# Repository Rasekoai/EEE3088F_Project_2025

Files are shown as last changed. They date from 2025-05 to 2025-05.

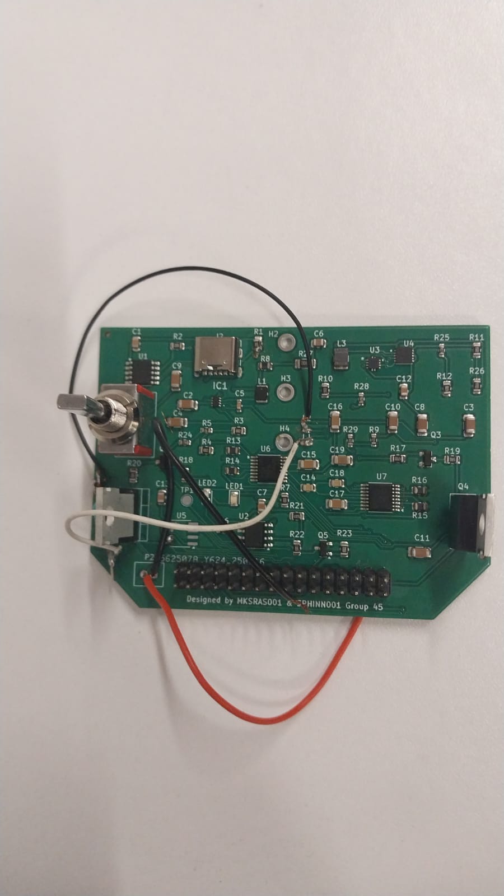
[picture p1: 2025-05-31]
Project files/PCB.jpg

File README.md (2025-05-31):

## EEE3088F 2025 Micromouse Power Module Project

## Overview
This repository contains the design and implementation of the power subsystem for the Micro-mouse robot. The power subsystem is designed to efficiently manage power distribution to motors and provide USB connectivity for control interfaces.

## System Requirements

### Motor Control
- **Bidirectional operation** of up to 4 motors 
- **Motor specifications**:
  - 2x main brushed DC motors - 200mA max current draw at 15V battery
  - 2x auxiliary motors - 50mA each

### Battery Management
- **Battery**: 4.2V Lithium ion battery 
- **INA219** implementation for monitoring the battery on the I2C Bus
- **Charging**: Support for battery charging from the 5V input 
- **Dual charging modes**:
  - Higher charging current for battery (600mA)
  - Lower charging current for battery (100mA)

### USB Interface
- **Integrated USB-C port** for 5V output from the USB Host

### Power Control
- **ON/OFF switch**:
  - OFF state: Battery draw <50μA
  - ON state: Robot peak current is 1A
  - Switch turns on both 5V and 3V3

## Project Structure
This repository contains:
- Circuit schematic
- PCB design
- Datasheets for ICs used

## Assessment Information
This project is part of a group assignment. While the interim and final design reports are assessed as a group, individual contributions to the design sections will be evaluated separately.

## Contributors
- Rasekoai Mokose - student no: MKSRAS001
- Innocent Mkhonta - student no: SPHINN001

                                                                                                                                                                                                                                                                                                                                                                                                                                                                                                                                                                                                                                                                                                                                                                                                                                                                                                                                                                                                                                                                                                                                                                                                                                                                                                                                                                                                                                                                                                                                                                                                                                                                                                                                                                                                                                                                                                                                                                                                                                                                                                                                                                                                                                                                                                                                                                                                                                                                                                                                                                                                                                                                                                                                                                                                                                                                                                                                                                                                                                                                                                                                                                                                                                                                                                                                                                                                                                                                                                                                                                                                                                                                                                                                                                                                                                                                                                                                                                                                                                                                                                                                                                                                                                                                                                                                                                                                                                                                                                                                                                                                                                                                                                                                                                                                                                                                                                                                                                                                                                                                                                                                                                                                                                                                                                                                                                                                                                                                                                                                                                                                                                                                                                                                                                                                                                                                                                                                                                                                                                                                                                                                                                                                                                                                                                                                                                                                                                                                                                                                                                                                                                                                                                                                                                                                                                                                                                                                                                                                                                                                                                                                                                                                                                                                                                                                                                                                                                                                                                                                                                                                                                                                                                                                                                                                                                                                                                                                                                                                                                                                                                                                                                                                                                                                                                                                                                                                                                                                                                                                                                                                                                                                                                                                                                                                                                                                                                                                                                                                                                                                                                                                                                                                                                                                                                                                                                                                                                                                                                                                                                                                                                                                                                                                                                                                                                                                                                                                                                                                                                                                                                                                                                                                                                                                                                                                                                                                                                                                                                                                                                                                                                                                                                                                                                                                                                                                                                                                                                                                                                                                                                                                                                                                                                                                                                                                                                                                                                                                                                                                                                                                                                                                                                                                                                                                                                                                                                                                                                                                                                                                                                                                                                                                                                                                                                                                                                                                                                                                                                                                                                                                                                                                                                                                                                                                                                                                                                                                                                                                                                                                                                                                                                                                                                                                                                                                                                                                                                                                                                                                                                                                                                                                                                                                                                                                                                                                                                                                                                                                                                                                                                                                                                                                                                                                                                                                                                                                                                                                                                                                                                                                                                                                                                                                                                                                                                                                                                                                                                                                                                                                                                                                                                                                                                                                                                                                                                                                                                                                                                                                                                                                                                                                                                                                                                                                                                                                                                                                                                                                                                                                                                                                                                                                                                                                                                                                                                                                                                                                                                                                                                                                                                                                                                                                                                                                                                                                                                                                                                                                                                                                                                                                                                                                                                                                                                                                                                                                                                                                                                                                                                                                                                                                                                                                                                                                                                                                                                                                                                                                                                                                                                                                                                                                                                                                                                                                                                                                                                                                                                                                                                                                                                                                                                                                                                                                                                                                                                                                                                                                                                                                                                                                                                                                                                                                                                                                                                                                                                                                                                                                                                                                                                                                                                                                                                                                                                                                                                                                                                                                                                                                                                                                                                                                                                                                                                                                                                                                                                                                                                                                                                                                                                                                                                                                                                                                                                                                                                                                                                                                                                                                                                                                                                                                                                                                                                                                                                                                                                                                                                                                                                                                                                                                                                                                                                                                                                                                                                                                                                                                                                                                                                                                                                                                                                                                                                                                                                                                                                                                                                                                                                                                                                                                                                                                                                                                                                                                                                                                                                                                                                                                                                                                                                                                                                                                                                                                                                                                                                                                                                                                                                                                                                                                                                                                                                                                                                                                                                                                                                                                                                                                                                                                                                                                                                                                                                                                                                                                                                                                                                                                                                                                                                                                                                                                                                                                                                                                                                                                                                                                                                                                                                                                                                                                                                                                                                                                                                                                                                                                                                                                                                                                                                                                                                                                                                                                                                                                                                                                                                                                                                                                                                                                                                                                                                                                                                                                                                                                                                                                                                                                                                                                                                                                                                                                                                                                                                                                                                                                                                                                                                                                                                                                                                                                                                                                                                                                                                                                                                                                                                                                                                                                                                                                                                                                                                                                                                                                                                                                                                                                                                                                                                                                                                                                                                                                                                                                                                                                                                                                                                                                                                                                                                                                                                                                                                                                                                                                                                                                                                                                                                                                                                                                                                                                                                                                                                                                                                                                                                                                                                                                                                                                                                                                                                                                                                                                                                                                                                                                                                                                                                                                                                                                                                                                                                                                                                                                                                                                                                                                                                                                                                                                                                                                                                                                                                                                                                                                                                                                                                                                                                                                                                                                                                                                                                                                                                                                                                                                                                                                                                                                                                                                                                                                                                                                                                                                                                                                                                                                                                                                                                                                                                                                                                                                                                                                                                                                                                                                                                                                                                                                                                                                                                                                                                                                                                                                                                                                                                                                                                                                                                                                                                                                                                                                                                                                                                                                                                                                                                                                                                                                                                                                                                                                                                                                                                                                                                                                                                                                                                                                                                                                                                                                                                                                                                                                                                                                                                                                                                                                                                                                                                                                                                                                                                                                                                                                                                                                                                                                                                                                                                                                                                                                                                                                                                                                                                                                                                                                                                                                                                                                                                                                                                                                                                                                                                                                                                                                                                                                                                                                                                                                                                                                                                                                                                                                                                                                                                                                                                                                                                                                                                                                                                                                                                                                                                                                                                                                                                                                                                                                                                                                                                                                                                                                                                                                                                                                                                                                                                                                                                                                                                                                                                                                                                                                                                                                                                                                                                                                                                                                                                                                                                                                                                                                                                                                                                                                                                                                                                                                                                                                                                                                                                                                                                                                                                                                                                                                                                                                                                                                                                                                                                                                                                                                                                                                                                                                                                                                                                                                                                                                                                                                                                                                                                                                                                                                                                                                                                                                                                                                                                                                                                                                                                                                                                                                                                                                                                                                                                                                                                                                                                                                                                                                                                                                                                                                                                                                                                                                                                                                                                                                                                                                                                                                                                                                                                                                                                                                                                                                                                                                                                                                                                                                                                                                                                                                                                                                                                                                                                                                                                                                                                                                                                                                                                                                                                                                                                                                                                                                                                                                                                                                                                                                                                                                                                                                                                                                                                                                                                                                                                                                                                                                                                                                                                                                                                                                                                                                                                                                                                                                                                                                                                                                                                                                                                                                                                                                                                                                                                                                                                                                                                                                                                                                                                                                                                                                                                                                                                                                                                                                                                                                                                                                                                                                                                                                                                                                                                                                                                                                                                                                                                                                                                                                                                                                                                                                                                                                                                                                                                                                                                                                                                                                                                                                                                                                                                                                                                                                                                                                                                                                                                                                                                                                                                                                                                                                                                                                                                                                                                                                                                                                                                                                                                                                                                                                                                                                                                                                                                                                                                                                                                                                                                                                                                                                                                                                                                                                                                                                                                                                                                                                                                                                                                                                                                                                                                                                                                                                                                                                                                                                                                                                                                                                                                                                                                                                                                                                                                                                                                                                                                                                                                                                                                                                                                                                                                                                                                                                                                                                                                                                                                                                                                                                                                                                                                                                                                                                                                                                                                                                                                                                                                                                                                                                                                                                                                                                                                                                                                                                                                                                                                                                                                                                                                                                                                                                                                                                                                                                                                                                                                                                                                                                                                                                                                                                                                                                                                                                                                                                                                                                                                                                                                                                                                                                                                                                                                                                                                                                                                                                                                                                                                                                                                                                                                                                                                                                                                                                                                                                                                                                                                                                                                                                                                                                                                                                                                                                                                                                                                                                                                                                                                                                                                                                                                                                                                                                                                                                                                                                                                                                                                                                                                                                                                                                                                                                                                                                                                                                                                                                                                                                                                                                                                                                                                                                                                                                                                                                                                                                                                                                                                                                                                                                                                                                                                                                                                                                                                                                                                                                                                                                                                                                                                                                                                                                                                                                                                                                                                                                                                                                                                                                                                                                                                                                                                                                                                                                                                                                                                                                                                                                                                                                                                                                                                                                                                                                                                                                                                                                                                                                                                                                                                                                                                                                                                                                                                                                                                                                                                                                                                                                                                                                                                                                                                                                                                                                                                                                                                                                                                                                                                                                                                                                                                                                                                                                                                                                                                                                                                                                                                                                                                                                                                                                                                                                                                                                                                                                                                                                                                                                                                                                                                                                                                                                                                                                                                                                                                                                                                                                                                                                                                                                                                                                                                                                                                                                                                                                                                                                                                                                                                                                                                                                                                                                                                                                                                                                                                                                                                                                                                                                                                                                                                                                                                                                                                                                                                                                                                                                                                                                                                                                                                                                                                                                                                                                                                                                                                                                                                                                                                                                                                                                                                                                                                                                                                                                                                                                                                                                                                                                                                                                                                                                                                                                                                                                                                                                                                                                                                                                                                                                                                                                                                                                                                                                                                                                                                                                                                                                                                                                                                                                                                                                                                                                                                                                                                                                                                                                                                                                                                                                                                                                                                                                                                                                                                                                                                                                                                                                                                                                                                                                                                                                                                                                                                                                                                                                                                                                                                                                                                                                                                                                                                                                                                                                                                                                                                                                                                                                                                                                                                                                                                                                                                                                                                                                                                                                                                                                                                                                                                                                                                                                                                                                                                                                                                                                                                                                                                                                                                                                                                                                                                                                                                                                                                                                                                                                                                                                                                                                                                                                                                                                                                                                                                                                                                                                                                                                                                                                                                                                                                                                                                                                                                                                                                                                                                                                                                                                                                                                                                                                                                                                                                                                                                                                                                                                                                                                                                                                                                                                                                                                                                                                                                                                                                                                                                                                                                                                                                                                                                                                                                                                                                                                                                                                                                                                                                                                                                                                                                                                                                                                                                                                                                                                                                                                                                                                                                                                                                                                                                                                                                                                                                                                                                                                                                                                                                                                                                                                                                                                                                                                                                                                                                                                                                                                                                                                                                                                                                                                                                                                                                                                                                                                                                                                                                                                                                                                                                                                                                                                                                                                                                                                                                                                                                                                                                                                                                                                                                                                                                                                                                                                                                                                                                                                                                                                                                                                                                                                                                                                                                                                                                                                                                                                                                                                                                                                                                                                                                                                                                                                                                                                                                                                                                                                                                                                                                                                                                                                                                                                                                                                                                                                                                                                                                                                                                                                                                                                                                                                                                                                                                                                                                                                                                                                                                                                                                                                                                                                                                                                                                                                                                                                                                                                                                                                                                                                                                                                                                                                                                                                                                                                                                                                                                                                                                                                                                                                                                                                                                                                                                                                                                                                                                                                                                                                                                     -

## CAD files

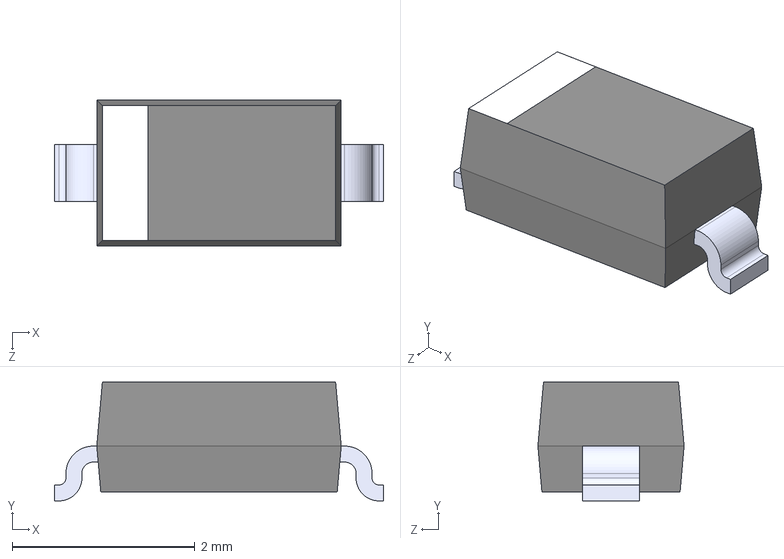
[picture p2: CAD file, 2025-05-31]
Footprints Library/BZT52C3V3-GRHG/BZT52C3V3-GRHG.step
3.60 x 1.30 x 1.60 mm

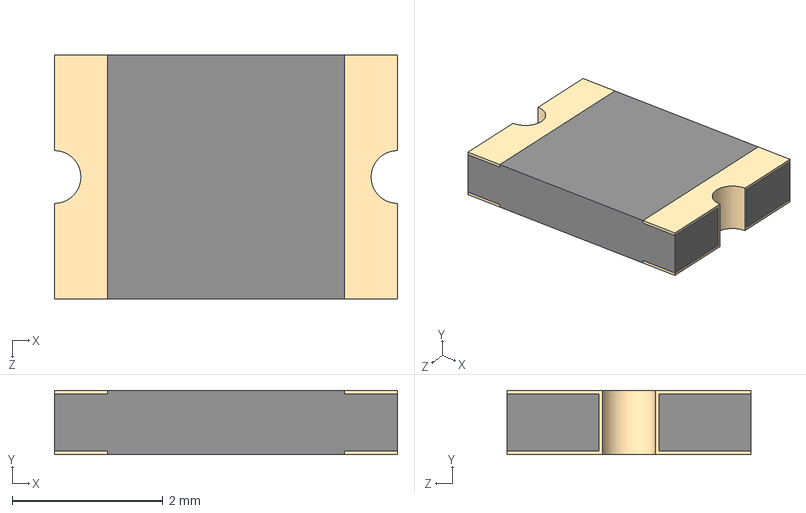
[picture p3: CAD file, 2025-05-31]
Footprints Library/MF-MSMF150_12-2/MF-MSMF150_12-2.step
4.55 x 0.85 x 3.24 mm

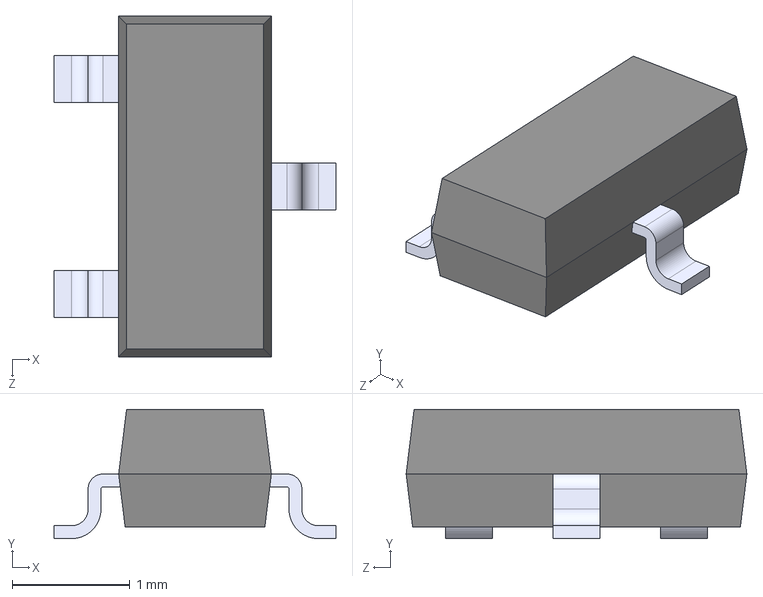
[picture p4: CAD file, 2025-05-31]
Footprints Library/MMBT5551/MMBT5551.step
2.40 x 1.10 x 2.90 mm

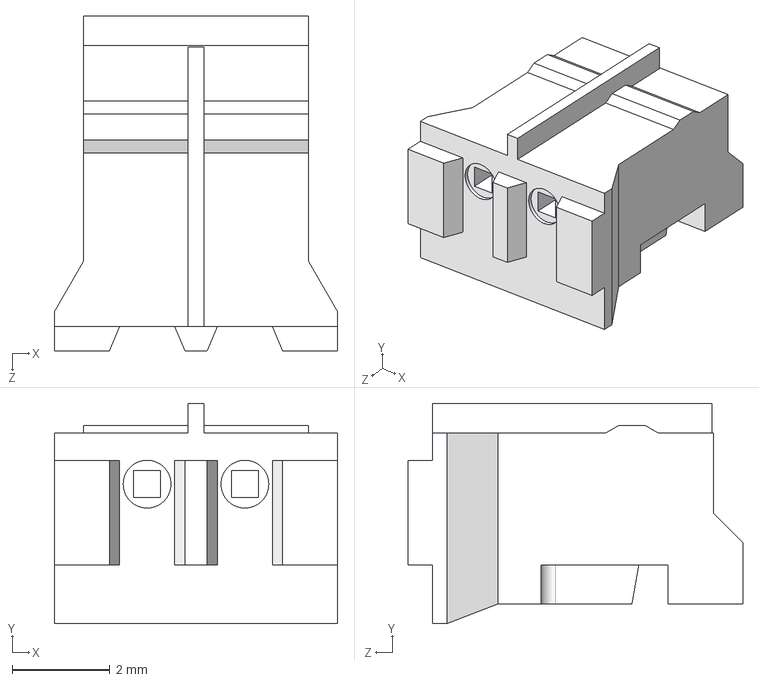
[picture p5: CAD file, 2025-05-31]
Footprints Library/PHR-2/PHR-2.step
5.80 x 4.50 x 6.85 mm

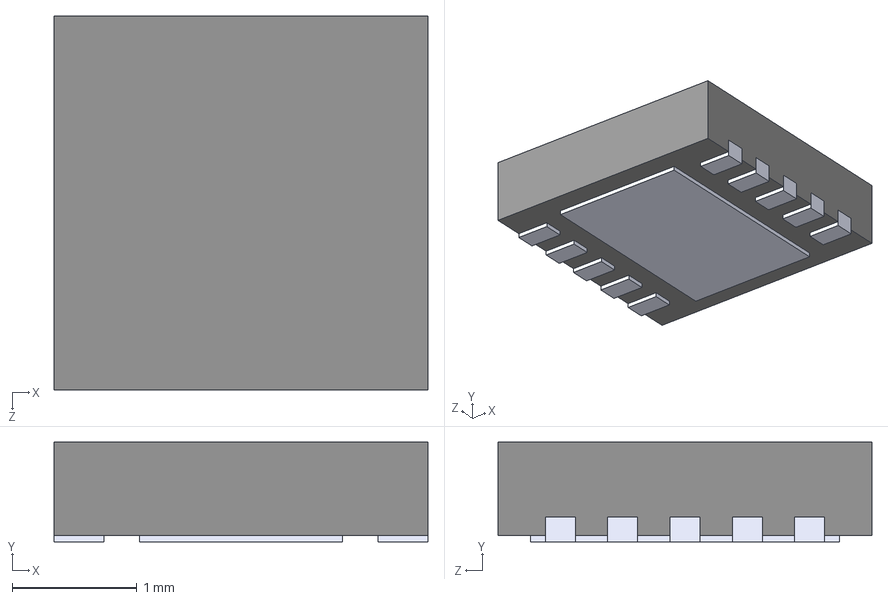
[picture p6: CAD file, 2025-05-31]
Footprints Library/RT6150AGQW/RT6150AGQW.step
3.00 x 0.8 x 3.00 mm

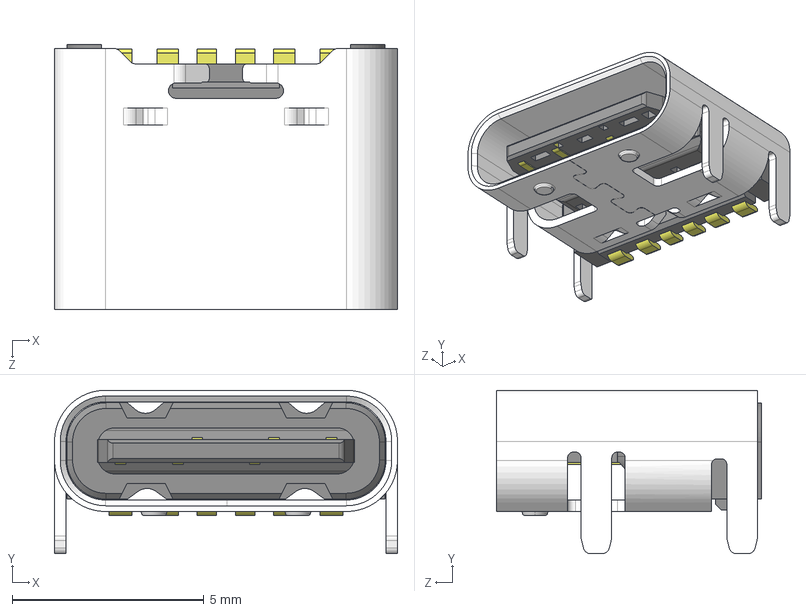
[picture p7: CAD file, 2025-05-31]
Footprints Library/UJC-HP-3-SMT-TR/UJC-HP-3-SMT-TR.step
8.94 x 4.26 x 6.90 mm

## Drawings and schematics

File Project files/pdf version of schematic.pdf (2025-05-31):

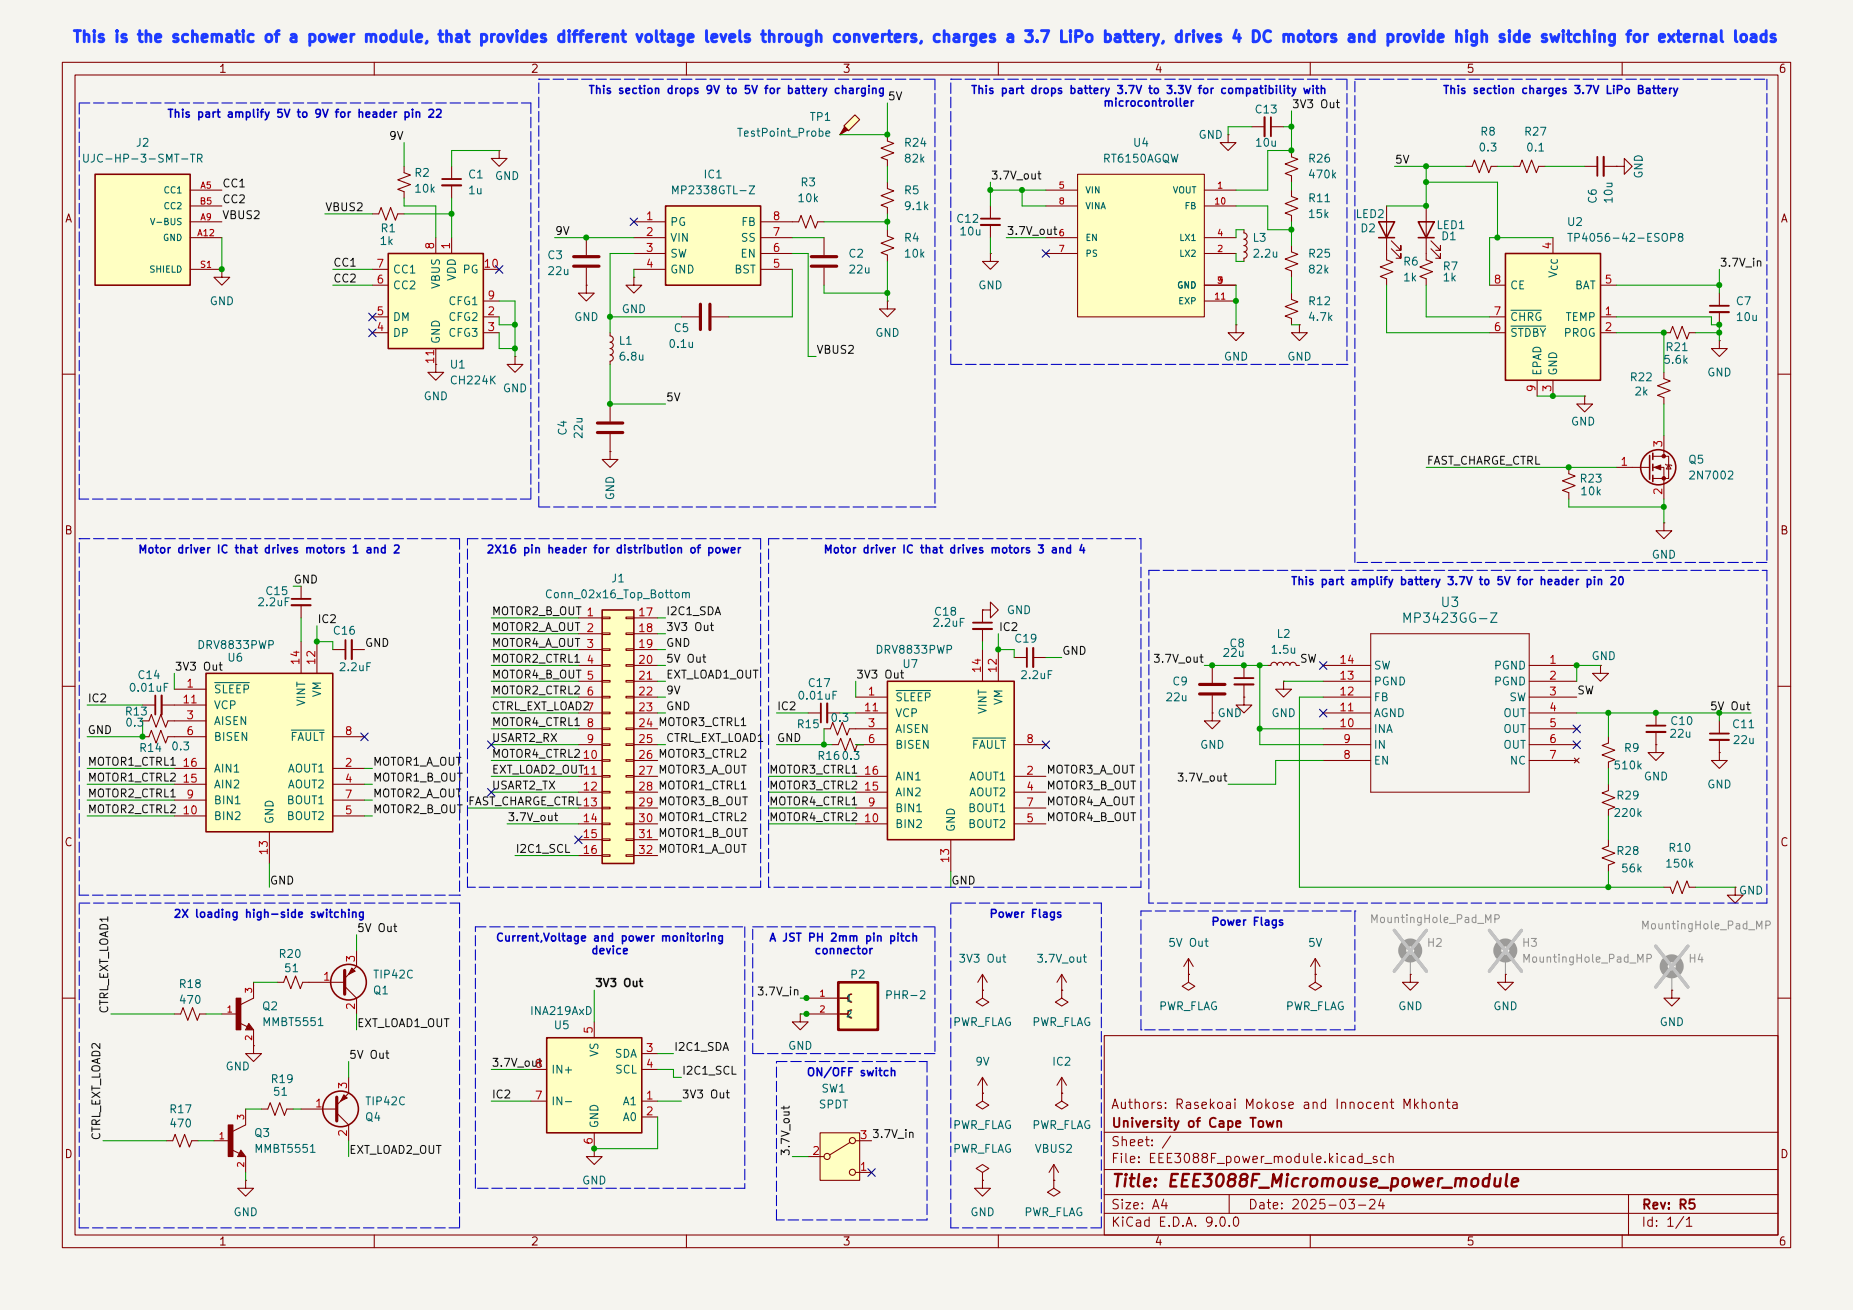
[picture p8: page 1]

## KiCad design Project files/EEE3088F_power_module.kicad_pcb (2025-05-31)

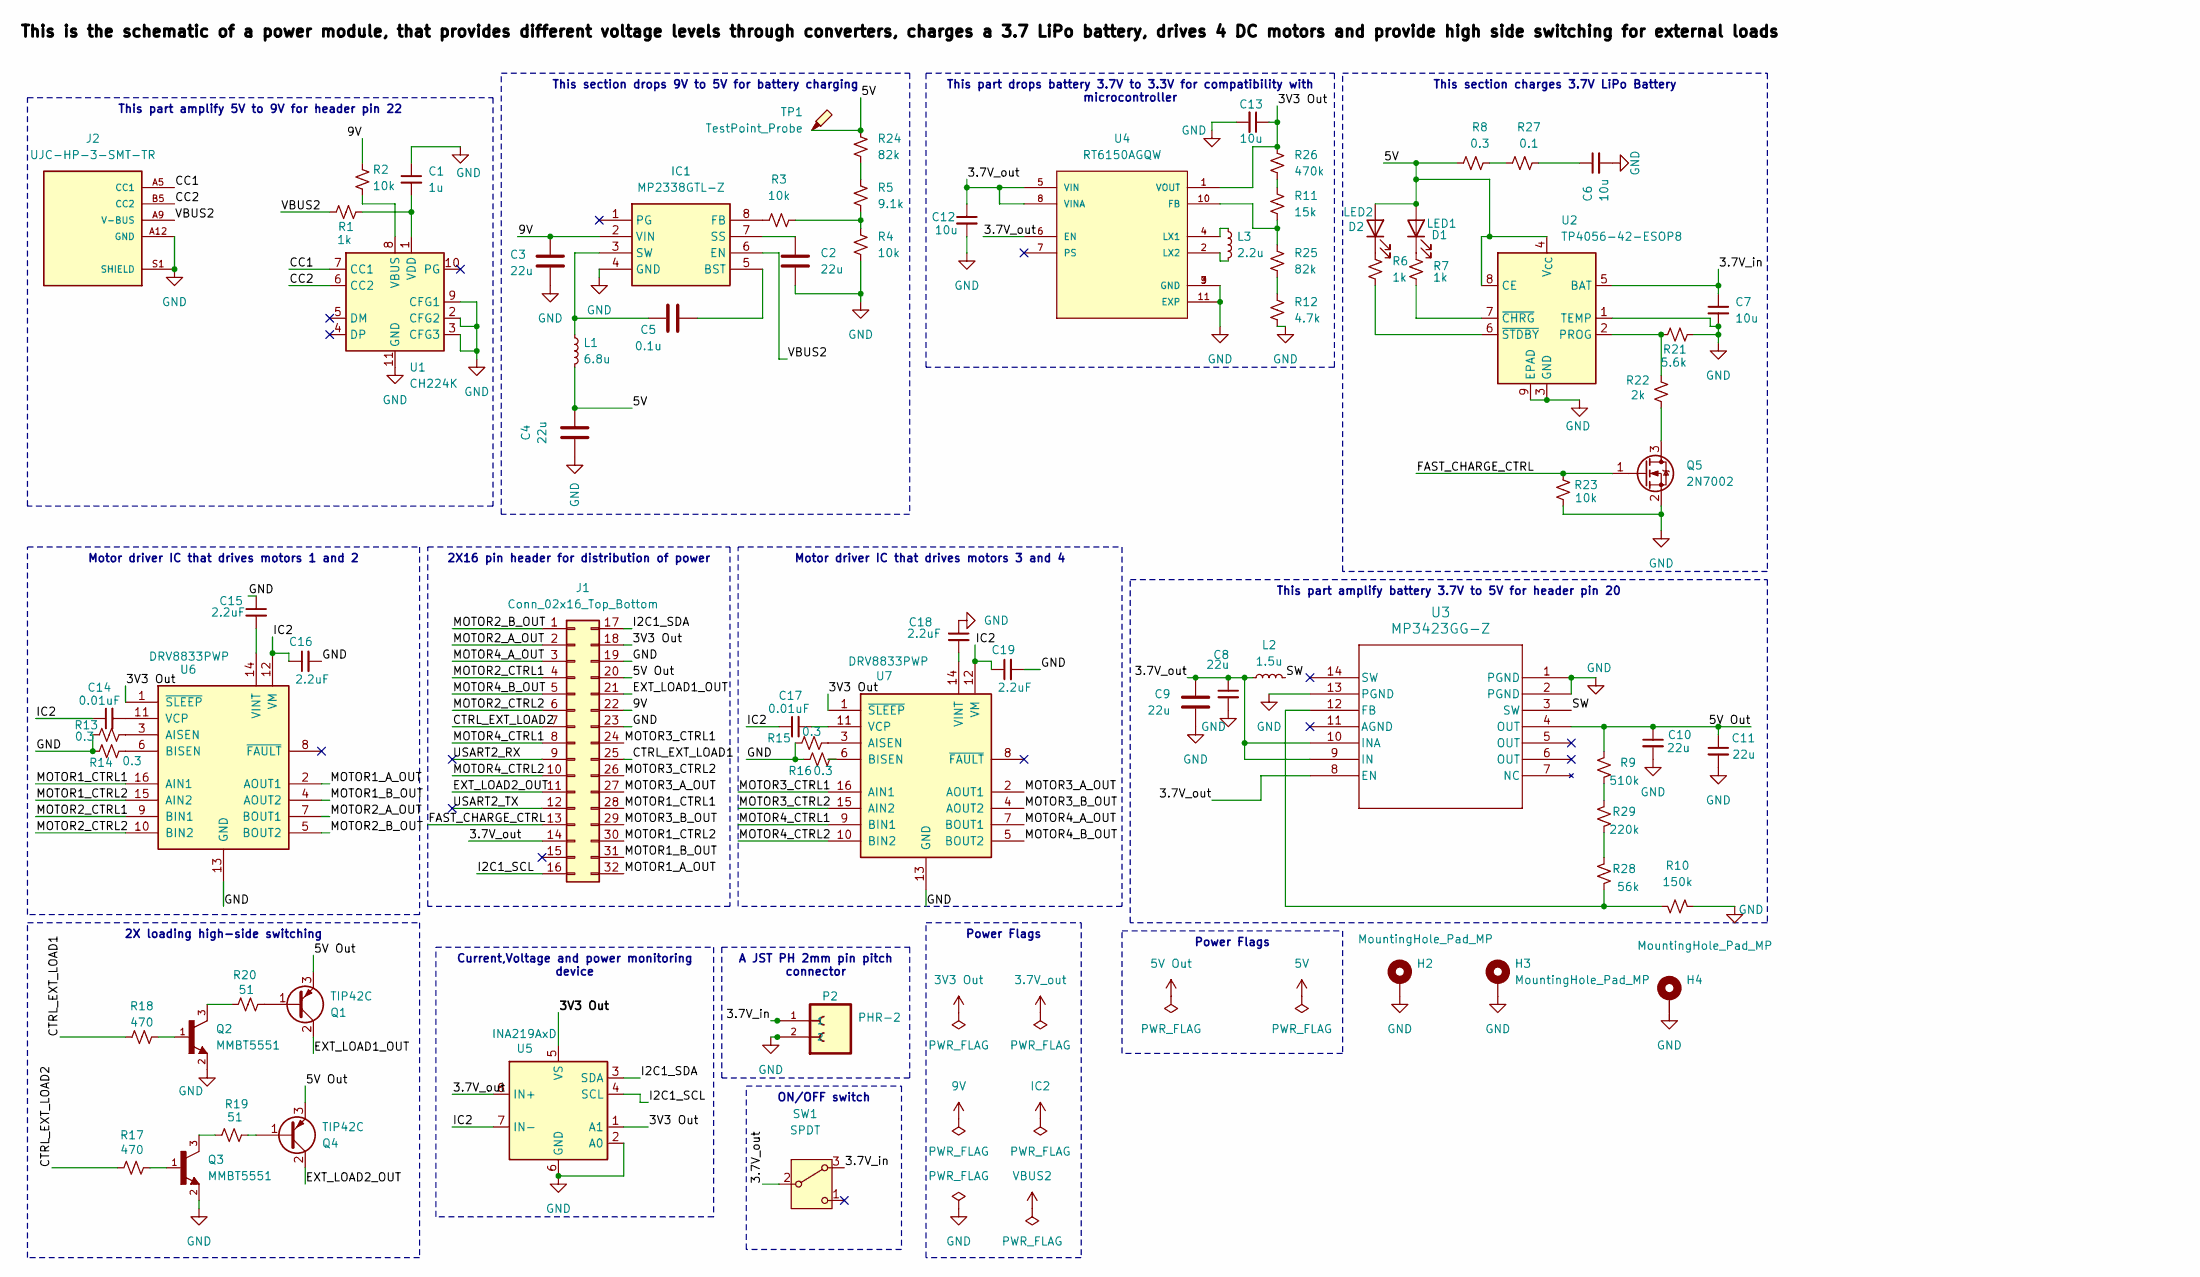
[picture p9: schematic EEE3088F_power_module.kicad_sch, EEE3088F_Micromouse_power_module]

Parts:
C1: 1u; C_0402_1005Metric
C2, C3, C4, C8, C9, C10, C11: 22u; C_1206_3216Metric
C5: 0.1u; C_0603_1608Metric
C6, C7, C12, C13: 10u; C_0805_2012Metric
C14, C17: 0.01uF; C_0805_2012Metric
C15, C16, C18, C19: 2.2uF; C_1206_3216Metric
H2, H3, H4: MountingHole_Pad_MP; MountingHole_2.2mm_M2_ISO7380_Pad
IC1: MP2338GTL-Z; MP2338GTLZ; Mouser Part Number 946-MP2338GTL-Z
J1: Conn_02x16_Top_Bottom; PinHeader_2x16_P2.54mm_Vertical
J2: UJC-HP-3-SMT-TR; CUI_UJC-HP-3-SMT-TR; PARTREV 04/30/2020
L1: 6.8u; L_1008_2520Metric
L2: 1.5u; L_0805_2012Metric
L3: 2.2u; L_1210_3225Metric
LED1: D1; LED_0805_2012Metric
LED2: D2; LED_0805_2012Metric
P2: PHR-2; JST_PHR-2
Q1, Q4: TIP42C; TO-220-3_Vertical
Q2, Q3: MMBT5551; SOT23-3; DigiKey_Part_Number 2156-MMBT5551-ND
Q5: 2N7002; SOT-23
R1, R6, R7: 1k; R_0805_2012Metric
R2, R3, R4, R23: 10k; R_0805_2012Metric
R5: 9.1k; R_0603_1608Metric
R8, R13, R14, R15, R16: 0.3; R_0805_2012Metric
R9: 510k; R_0603_1608Metric
R10: 150k; R_0805_2012Metric
R11: 15k; R_0805_2012Metric
R12: 4.7k; R_0805_2012Metric
R17, R18: 470; R_0805_2012Metric
R19, R20: 51; R_0805_2012Metric
R21: 5.6k; R_0805_2012Metric
R22: 2k; R_0805_2012Metric
R24: 82k; R_0805_2012Metric
R25: 82k; R_0603_1608Metric
R26: 470k; R_0805_2012Metric
R27: 0.1; R_1206_3216Metric
R28: 56k; R_0603_1608Metric
R29: 220k; R_0603_1608Metric
SW1: SPDT; NEWSWITCH
TP1: TestPoint_Probe; TestPoint_2mm
U1: CH224K; SSOP-10-1EP_3.9x4.9mm_P1mm_EP2.1x3.3mm
U2: TP4056-42-ESOP8; SOIC-8-1EP_3.9x4.9mm_P1.27mm_EP2.41x3.3mm_ThermalVias
U3: MP3423GG-Z; QFN14_MP3423_MNP
U4: RT6150AGQW; SON50P300X300X80-11N
U5: INA219AxD; SOIC-8_3.9x4.9mm_P1.27mm
U6, U7: DRV8833PWP; HTSSOP-16-1EP_4.4x5mm_P0.65mm_EP3.4x5mm_Mask2.46x2.31mm_The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

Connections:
3.7V_in: C7.1, P2.1, SW1.3 (A), U2.5 (BAT)
3.7V_out: C8.1, C9.1, C12.1, J1.14, L2.2, SW1.2 (B), U3.8 (EN), U3.9 (IN), U3.10 (INA), U4.5 (VIN), U4.6 (EN), U4.8 (VINA), U5.8 (IN+)
3V3 Out: C13.1, J1.18, R26.1, U4.1 (VOUT), U5.1 (A1), U5.5 (VS), U6.1 (~SLEEP), U7.1 (~SLEEP)
5V: C4.2, L1.2, LED1.2 (A), LED2.2 (A), R8.2, R24.1, TP1.1, U2.4 (V_{CC}), U2.8 (CE)
5V Out: C10.1, C11.1, J1.20, Q1.3 (E), Q4.3 (E), R9.2, U3.4 (OUT)
9V: C3.1, IC1.2 (VIN), J1.22, R2.1
/CC1: J2.A5 (CC1), U1.7 (CC1)
/CC2: J2.B5 (CC2), U1.6 (CC2)
/CTRL_EXT_LOAD1: J1.25, R18.1
/CTRL_EXT_LOAD2: J1.7, R17.1
/EXT_LOAD1_OUT: J1.21, Q1.2 (C)
/EXT_LOAD2_OUT: J1.11, Q4.2 (C)
/FAST_CHARGE_CTRL: J1.13, Q5.1 (G), R23.2
/I2C1_SCL: J1.16, U5.4 (SCL)
/I2C1_SDA: J1.17, U5.3 (SDA)
/MOTOR1_A_OUT: J1.32, U6.2 (AOUT1)
/MOTOR1_B_OUT: J1.31, U6.4 (AOUT2)
/MOTOR1_CTRL1: J1.28, U6.16 (AIN1)
/MOTOR1_CTRL2: J1.30, U6.15 (AIN2)
/MOTOR2_A_OUT: J1.2, U6.7 (BOUT1)
/MOTOR2_B_OUT: J1.1, U6.5 (BOUT2)
/MOTOR2_CTRL1: J1.4, U6.9 (BIN1)
/MOTOR2_CTRL2: J1.6, U6.10 (BIN2)
/MOTOR3_A_OUT: J1.27, U7.2 (AOUT1)
/MOTOR3_B_OUT: J1.29, U7.4 (AOUT2)
/MOTOR3_CTRL1: J1.24, U7.16 (AIN1)
/MOTOR3_CTRL2: J1.26, U7.15 (AIN2)
/MOTOR4_A_OUT: J1.3, U7.7 (BOUT1)
/MOTOR4_B_OUT: J1.5, U7.5 (BOUT2)
/MOTOR4_CTRL1: J1.8, U7.9 (BIN1)
/MOTOR4_CTRL2: J1.10, U7.10 (BIN2)
/RESV: J1.15
/USART2_RX: J1.9
/USART2_TX: J1.12
GND: C1.1, C2.2, C3.2, C4.1, C6.2, C7.2, C8.2, C9.2, C10.2, C11.2, C12.2, C13.2, C15.1, C16.2, C18.1, C19.2, H2.MP, H3.MP, H4.MP, IC1.4 (GND), J1.19, J1.23, J2.A12 (GND), J2.S1 (SHIELD), P2.2, Q2.2, Q3.2, Q5.2 (S), R4.2, R10.2, R12.2, R13.1, R14.1, R15.1, R16.1, R21.2, R23.1, U1.2 (CFG2), U1.3 (CFG3), U1.9 (CFG1), U1.11 (GND), U2.1 (TEMP), U2.3 (GND), U2.9 (EPAD), U3.1 (PGND), U3.2 (PGND), U3.13 (PGND), U4.3 (GND), U4.9 (GND), U4.11 (EXP), U5.2 (A0), U5.6 (GND), U6.13 (GND), U6.17 (GND), U7.13 (GND), U7.17 (GND)
IC2: C14.1, C16.1, C17.1, C19.1, U5.7 (IN-), U6.12 (VM), U7.12 (VM)
unnamed: C6.1, R27.1
unnamed: C5.2, IC1.5 (BST)
unnamed: IC1.8 (FB), R3.1
unnamed: C2.1, IC1.7 (SS)
unnamed: C5.1, IC1.3 (SW), L1.1
unnamed: L2.1, U3.3 (SW), U3.14 (SW)
unnamed: LED1.1 (K), R7.1
unnamed: LED2.1 (K), R6.1
unnamed: Q1.1 (B), R20.2
unnamed: Q2.1, R18.2
unnamed: Q2.3, R20.1
unnamed: Q3.1, R17.2
unnamed: Q3.3, R19.1
unnamed: Q4.1 (B), R19.2
unnamed: Q5.3 (D), R22.2
unnamed: R3.2, R4.1, R5.2
unnamed: R11.1, R26.2
unnamed: R12.1, R25.2
unnamed: R5.1, R24.2
unnamed: R8.1, R27.2
unnamed: R28.2, R29.1
unnamed: R9.1, R29.2
unnamed: R2.2, U1.8 (VBUS)
unnamed: C1.2, R1.2, U1.1 (VDD)
unnamed: R21.1, R22.1, U2.2 (PROG)
unnamed: R7.2, U2.7 (~CHRG)
unnamed: R6.2, U2.6 (~STDBY)
unnamed: R10.1, R28.1, U3.12 (FB)
unnamed: R11.2, R25.1, U4.10 (FB)
unnamed: L3.1, U4.4 (LX1)
unnamed: L3.2, U4.2 (LX2)
unnamed: R13.2, U6.3 (AISEN)
unnamed: R14.2, U6.6 (BISEN)
unnamed: C14.2, U6.11 (VCP)
unnamed: C15.2, U6.14 (VINT)
unnamed: R15.2, U7.3 (AISEN)
unnamed: R16.2, U7.6 (BISEN)
unnamed: C17.2, U7.11 (VCP)
unnamed: C18.2, U7.14 (VINT)
VBUS2: IC1.6 (EN), J2.A9 (V-BUS), R1.1

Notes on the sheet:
Power Flags
This section charges 3.7V LiPo Battery
Motor driver IC that drives motors 3 and 4
This part amplify 5V to 9V for header pin 22
2X16 pin header for distribution of power
Motor driver IC that drives motors 1 and 2
ON/OFF switch
A JST PH 2mm pin pitch connector
Current,Voltage and power monitoring device
This part drops battery 3.7V to 3.3V for compatibility with microcontroller
Power Flags
This part amplify battery 3.7V to 5V for header pin 20
This section drops 9V to 5V for battery charging
2X loading high-side switching

Board: 2 copper layers, 74 parts (1 on the bottom side), 73 nets, no tracks yet.

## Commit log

2025-03-11 added a motor driver l298 datasheeet
2025-03-11 added a battery charging ic datasheeet
2025-05-31 these are the files for the project
    [BZT52C3V3-GRHG.step, EEE3088F_power_module.dsn, EEE3088F_power_module.kicad_pcb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]
2025-05-31 added a real PCB picture to the repo
